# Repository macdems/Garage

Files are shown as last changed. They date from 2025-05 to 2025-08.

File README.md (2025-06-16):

# Garage ESPHome Controller

## Overview

This project provides a comprehensive solution for automating and monitoring a garage door using the **ESP32-C3 Super Mini** microcontroller. The controller integrates seamlessly with **Home Assistant** via **ESPHome**, enabling smart home automation and remote control.

## Key Features

- **ESPHome integration** for easy Home Assistant setup and monitoring
- **Current sensor** for accurate detection of fully open/closed garage door states by monitoring motor current
- **External push button** support for manual operation
- **12V remote receiver** compatibility (e.g., [INEL ORS-X1T](https://allegro.pl/oferta/radiowy-sterownik-do-bram-inel-ors-x1t-10559594952)) for remote control
- **Compact hardware design** fits standard enclosure with receiver
- **Complete KiCAD hardware design files** and **ready-to-use ESPHome YAML configuration**

## Hardware Requirements and Bill of Materials (BOM)

| ID | Item | Quantity | Description |
| --- | --- | --- | --- |
| U1 | LM2940T-5.0/NOPB vaoltage stabilizer | 1 | Package TO-220-3, output voltage 5V |
| U2 | ACS712xLCTR-05B current sensor | 1 | For motor current measurement <https://www.aliexpress.com/item/1005006830307802.html>, SOIC-8 package |
| U3 | LM358 operational amplifier | 1 | Package DIP-8 W7.62mm |
| U4 | ESP32-C3 Super Mini | 1 | Main controller (recommended version with external antenna socket for optimal WiFi performance) |
| K1,K2 | Relay module JW1aFSN-DC12V | 1 | For garage door motor control |
| C1 | Capacitor 470nF | 1 | Capacitor THT: D4.3mm W1.9mm P5.00mm |
| C2 | Capacitor 22µF | 1 | Capacitor THT: D4.5mm P2.50mm |
| C3 | Capacitor 1nF | 1 | Capacitor THT: D4.3mm W1.9mm P5.00mm |
| C4 | Capacitor 22uF | 1 | Capacitor THT: D4.5mm P2.50mm |
| D1,D2 | Diode 1N4148 | 2 | Diode 1N4148 THT: DO-35 SOD27 P7.62mm Horizontal |
| HS1 | Heatsink | 1 | Heatsink for TO-220 <https://www.aliexpress.com/item/1005006082544471.html> |
| J1 | AC power connector | 1 | TerminalBlock MetzConnect: TerminalBlock MetzConnect Type101 RT01602HBWC 1x02 P5.08mm Horizontal |
| J2 | Gate connector | 1 | TerminalBlock MetzConnect: TerminalBlock MetzConnect Type101 RT01603HBWC 1x03 P5.08mm Horizontal |
| K1,K2 | Relay SPST-NO | 2 | Relay THT: Relay SPST Panasonic JW1 FormA |
| PS1 | HLK-30M12C 230V power supply | 1 | Converter ACDC: Converter ACDC Hi-Link HLK-30M12C |
| Q1,Q2 | Transistor 2N5551 | 2 | Package TO SOT THT: TO-92 Inline |
| R1,R2,R5,R6 | Resistors 10k | 4 | Resistor THT: R Axial DIN0207 L6.3mm D2.5mm P7.62mm Horizontal |
| R3,R4 | Resistor 68k | 2 | Resistor THT: R Axial DIN0207 L6.3mm D2.5mm P7.62mm Horizontal |
| R7 | Resistor 4k7 | 1 | Resistor THT: R Axial DIN0207 L6.3mm D2.5mm P7.62mm Horizontal |
| R8 | Resistor 5k6 | 1 | Resistor THT: R Axial DIN0207 L6.3mm D2.5mm P7.62mm Horizontal |
| RV1 | 10k Potentiometer | 1 | Potentiometer THT: Potentiometer Runtron RM-065 Vertical |
| SW1 | Button connector | 1 | TerminalBlock MetzConnect: TerminalBlock MetzConnect Type101 RT01602HBWC 1x02 P5.08mm Horizontal |
| SW2 | Radio remote receiver connector | 1 | TerminalBlock MetzConnect: TerminalBlock MetzConnect Type101 RT01604HBWC 1x04 P5.08mm Horizontal |

## Electric circuit diagram

Electric schematic

## Assembly & Integration

1. Use the provided KiCAD or Gerber files to manufacture the PCB. I recommend using [JLCPCB](https://jlcpcb.com) service, which offers high quality PCB boards for only $2.
2. Assemble the PCB using the schematic above.
3. Install all components in the enclosure, connect 230V power and your garage doors to the terminals. Optionally, you may connect external button or radio remote receiver.
4. Adjust the RV potentiometer such that there is 0V on R7.
5. Flash the ESP32-C3 Super Mini with the included ESPHome configuration.
6. Add the device to Home Assistant via ESPHome for full smart home integration.

## Additional Recommendations

- Use the ESP32-C3 Super Mini version with an external antenna socket and connect a suitable WiFi antenna.
- Ensure all wiring and installation comply with local electrical safety standards.

## License

This project is open source. Please refer to the repository for detailed license information.

---

For further assistance, consult the repository documentation or open an issue.

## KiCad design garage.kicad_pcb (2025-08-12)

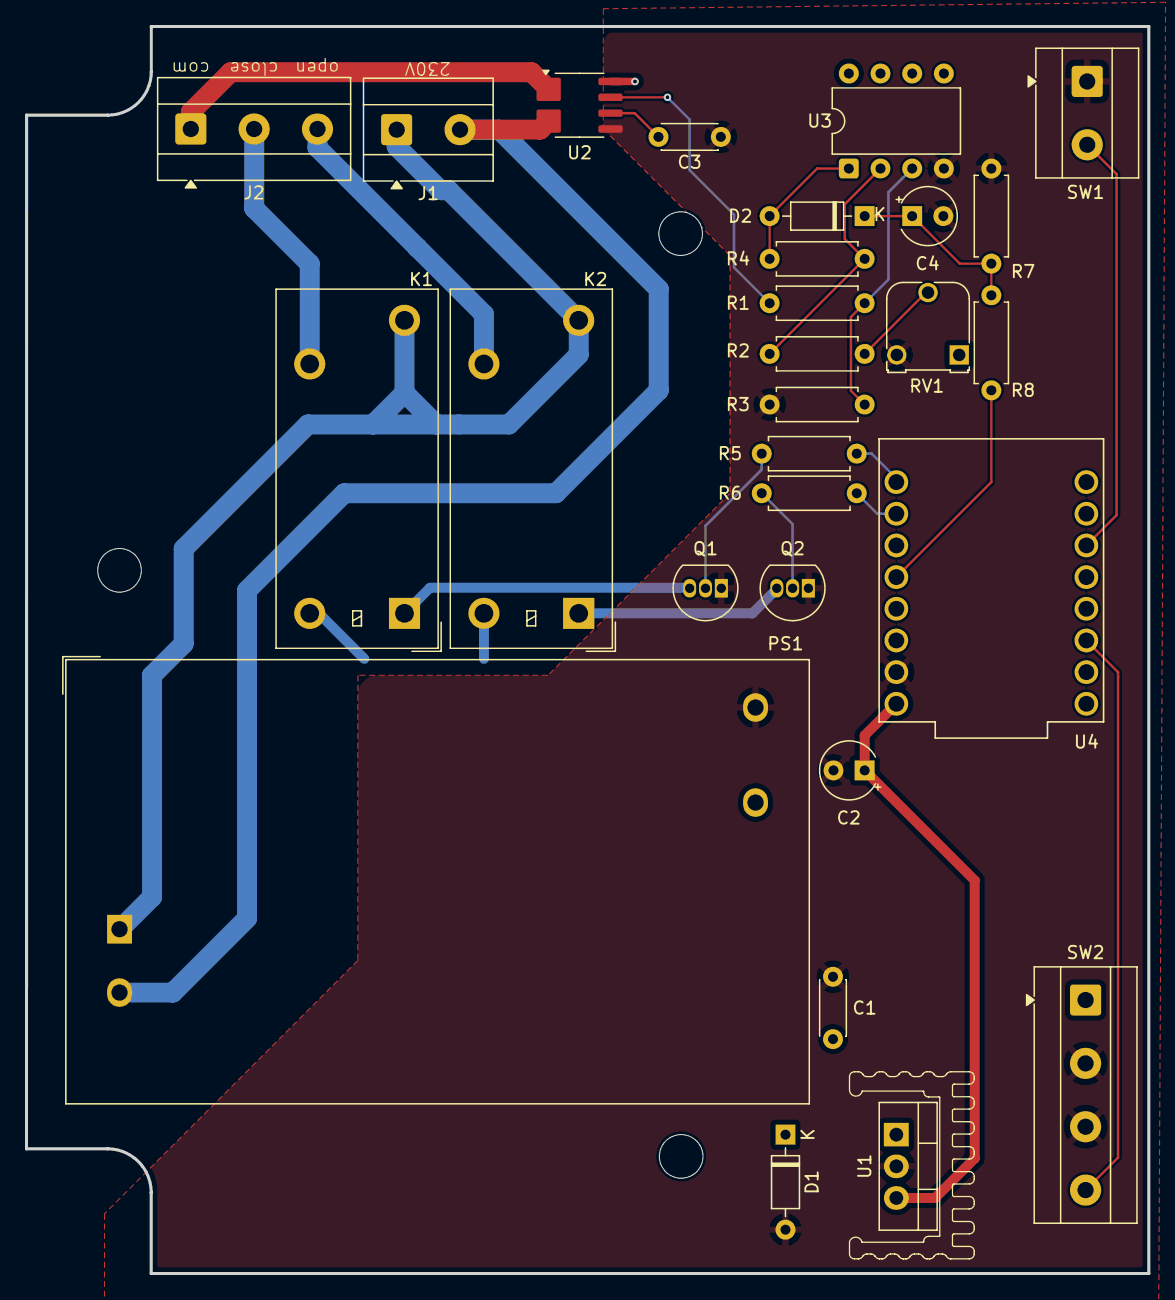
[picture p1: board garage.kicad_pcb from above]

Board: 2 copper layers, 90.0 x 100.0 mm, 32 parts (0 on the bottom side), 24 nets.

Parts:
C1: 470nF; C_Disc_D4.3mm_W1.9mm_P5.00mm
C2: 22µF; CP_Radial_Tantal_D4.5mm_P2.50mm
C3: 1nF; C_Disc_D4.3mm_W1.9mm_P5.00mm
C4: 22uF; CP_Radial_Tantal_D4.5mm_P2.50mm
D1, D2: 1N4148; D_DO-35_SOD27_P7.62mm_Horizontal
H1, H2, H3: MountingHole; MountingHole_3.5mm
HS1: Heatsink; Heatsink_T8WC_TO-220
J1: AC L/N; TerminalBlock_MetzConnect_Type101_RT01602HBWC_1x02_P5.08mm_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
J2: Gate; TerminalBlock_MetzConnect_Type101_RT01603HBWC_1x03_P5.08mm_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
K1, K2: Relay_SPST-NO; Relay_SPST_Panasonic_JW1_FormA
PS1: HLK-30M12C; Converter_ACDC_Hi-Link_HLK-30Mxx
Q1, Q2: 2N5551; TO-92_Inline
R1, R2, R5, R6: 10k; R_Axial_DIN0207_L6.3mm_D2.5mm_P7.62mm_Horizontal
R3, R4: 68k; R_Axial_DIN0207_L6.3mm_D2.5mm_P7.62mm_Horizontal
R7: 4k7; R_Axial_DIN0207_L6.3mm_D2.5mm_P7.62mm_Horizontal
R8: 5k6; R_Axial_DIN0207_L6.3mm_D2.5mm_P7.62mm_Horizontal
RV1: 10k; Potentiometer_Runtron_RM-065_Vertical
SW1: Button; TerminalBlock_MetzConnect_Type101_RT01602HBWC_1x02_P5.08mm_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
SW2: Radio; TerminalBlock_MetzConnect_Type101_RT01604HBWC_1x04_P5.08mm_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
U1: LM2940T-5.0/NOPB; TO-220-3_Vertical
U2: ACS712xLCTR-05B; SOIC-8_3.9x4.9mm_P1.27mm
U3: LM358; DIP-8_W7.62mm
U4: ESP32-C3_SUPERMINI_TH; MODULE_ESP32-C3_SUPERMINI_TH

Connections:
+5V: C2.1, RV1.1, U1.3 (OUTPUT), U2.8 (VCC), U3.8 (V+), U4.5V
+12V: C1.1, D1.1 (K), K1.8, K2.8, PS1.6 (+Vout), SW2.1 (L), U1.1 (INPUT)
/AC/NI: J2.1, U2.1 (IP+)
AC/G1: J2.2, K1.6
AC/G2: J2.3, K2.6
AC/L: J1.1, K1.4, K2.4, PS1.1 (AC/L)
AC/N: J1.2, PS1.2 (AC/N), U2.4 (IP-)
GND: C1.2, C2.2, C3.2, C4.2, D1.2 (A), PS1.3 (-Vout), Q1.1 (E), Q2.1 (E), R3.1, R7.2, RV1.3, SW1.1, SW2.2 (L), SW2.3 (1), U1.2 (GND), U2.5 (GND), U3.4 (V-), U4.G (GND)
unnamed: D2.2 (A), R4.1, U3.1
unnamed: C4.1, D2.1 (K), R7.1, R8.2
unnamed: Q1.2 (B), R5.1
unnamed: K1.1, Q1.3 (C)
unnamed: Q2.2 (B), R6.1
unnamed: K2.1, Q2.3 (C)
unnamed: R2.2, RV1.2
unnamed: SW2.4 (2), U4.7 (GPIO7)
unnamed: C3.1, U2.6 (FILTER)
unnamed: R1.1, U2.7 (VIOUT)
unnamed: R1.2, R3.2, U3.3 (+)
unnamed: R2.1, R4.2, U3.2 (-)
unnamed: R5.2, U4.0 (GPIO0)
unnamed: R6.2, U4.1 (GPIO1)
unnamed: R8.1, U4.3 (GPIO3)
unnamed: SW1.2, U4.10 (GPIO10)

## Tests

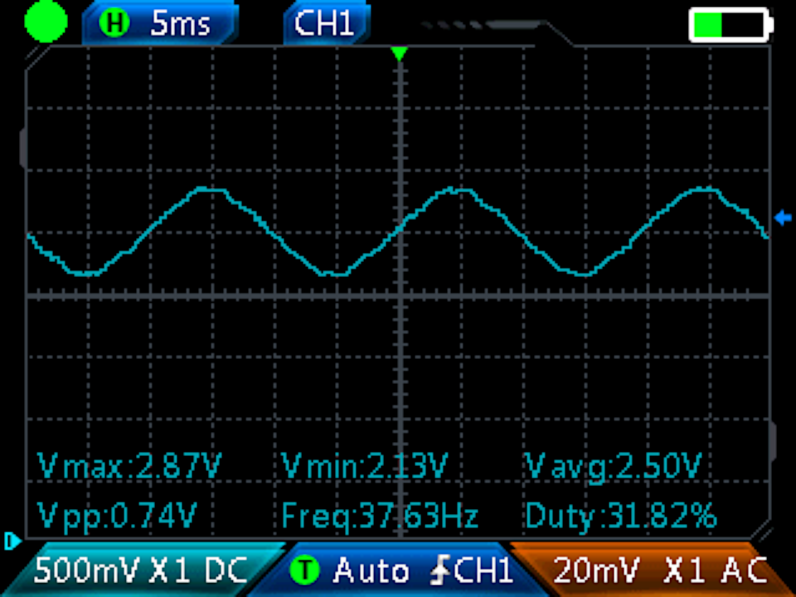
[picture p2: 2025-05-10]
acs712-measured.png

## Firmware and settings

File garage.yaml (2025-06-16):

# code: language=esphome
esphome:
  name: garage
  friendly_name: Garage door
  # on_boot:
  #   priority: -200
  #   then:
  #     - cover.close: garage_door

esp32:
  board: esp32-c3-devkitm-1
  variant: esp32c3
  framework:
    type: arduino

# Enable logging
logger:
  level: INFO

# Enable Home Assistant API
api:
  encryption:
    key: !secret api_encryption_key

ota:
  - platform: esphome
    password: !secret ota_password

wifi:
  ssid: !secret wifi_ssid
  password: !secret wifi_password

  ap:
    ssid: Garage door ESPHome
    password: !secret fallback_password

captive_portal:

globals:
  - id: disable_button
    type: bool
    restore_value: true
    initial_value: "false"
  - id: disable_remote
    type: bool
    restore_value: true
    initial_value: "false"

sensor:
  - platform: wifi_signal
    name: RSSI
    update_interval: 60s
    id: wifi_signal_strength

  - platform: adc
    pin: 3
    # name: Current
    attenuation: auto
    id: curent_sensor
    update_interval: 50ms
    entity_category: diagnostic
    device_class: current
    unit_of_measurement: A
    filters:
      - multiply: 1.2
      - sliding_window_moving_average:
          window_size: 4
          send_every: 2
          send_first_at: 2

binary_sensor:
  - platform: gpio
    name: Przycisk
    entity_category: diagnostic
    icon: mdi:electric-switch
    pin:
      number: 10
      mode: INPUT_PULLUP
      inverted: true
    id: push_button
    filters:
      - delayed_on_off: 100ms
    on_press:
      then:
        if:
          condition:
            lambda: 'return !id(disable_button);'
          then:
            - cover.toggle: garage_door

  - platform: gpio
    name: Pilot
    entity_category: diagnostic
    icon: mdi:electric-switch
    pin:
      number: 7
      mode: INPUT_PULLUP
      inverted: true
    id: radio_button
    filters:
      - delayed_on_off: 50ms
    on_press:
      then:
        if:
          condition:
            lambda: 'return !id(disable_remote);'
          then:
            - cover.toggle: garage_door

switch:
  - platform: gpio
    pin: 1
    id: relay_open
    restore_mode: ALWAYS_OFF
    interlock: &interlock [relay_open, relay_close]
    interlock_wait_time: 0.5s

  - platform: gpio
    pin: 0
    id: relay_close
    restore_mode: ALWAYS_OFF
    interlock: *interlock
    interlock_wait_time: 0.5s

  - platform: template
    name: Disable button
    entity_category: config
    icon: mdi:lock
    lambda: return id(disable_button);
    restore_mode: RESTORE_DEFAULT_OFF
    turn_on_action:
      - globals.set:
          id: disable_button
          value: "true"
    turn_off_action:
      - globals.set:
          id: disable_button
          value: "false"

  - platform: template
    name: Disabe remote
    entity_category: config
    icon: mdi:lock
    lambda: return id(disable_remote);
    restore_mode: RESTORE_DEFAULT_OFF
    turn_on_action:
      - globals.set:
          id: disable_remote
          value: "true"
    turn_off_action:
      - globals.set:
          id: disable_remote
          value: "false"

cover:
  - platform: current_based
    id: garage_door
    name: Garage
    device_class: garage
    open_sensor: curent_sensor
    close_sensor: curent_sensor
    open_moving_current_threshold: 0.2
    close_moving_current_threshold: 0.2
    open_obstacle_current_threshold: 1.8
    close_obstacle_current_threshold: 1.8
    open_action:
      - switch.turn_on: relay_open
    close_action:
      - switch.turn_on: relay_close
    stop_action:
      - switch.turn_off: relay_open
      - switch.turn_off: relay_close
    malfunction_detection: false
    max_duration: 45s
    open_duration: 22s
    close_duration: 21s

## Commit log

2025-04-26 PCB ready
    [Garaż.kicad_pcb, Garaż.kicad_sch, heatsink-silkscreen.dxf]
2025-05-07 Add simulation
    [Garaż.kicad_sch, symulacja.kicad_sch]
2025-05-10 Working project
    [Garaż.kicad_pcb, Garaż.kicad_sch, symulacja.kicad_sch]
2025-05-12 Remove broken separate pin for the button
    [garaż.yaml]
2025-05-12 Add software disable buttons options
2025-05-12 Fix restore mode of "disable" switches
    [garaż.yaml]
2025-05-14 Shorten remote reaction time to 50ms
    [garaż.yaml]
2025-06-16 Reorganize and make suitable for publication.
    [acs712-sim.kicad_sch, garage.kicad_pcb, garage.kicad_sch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]
2025-08-12 Design rules fix
    [garage.kicad_pcb, garage.kicad_sch]
